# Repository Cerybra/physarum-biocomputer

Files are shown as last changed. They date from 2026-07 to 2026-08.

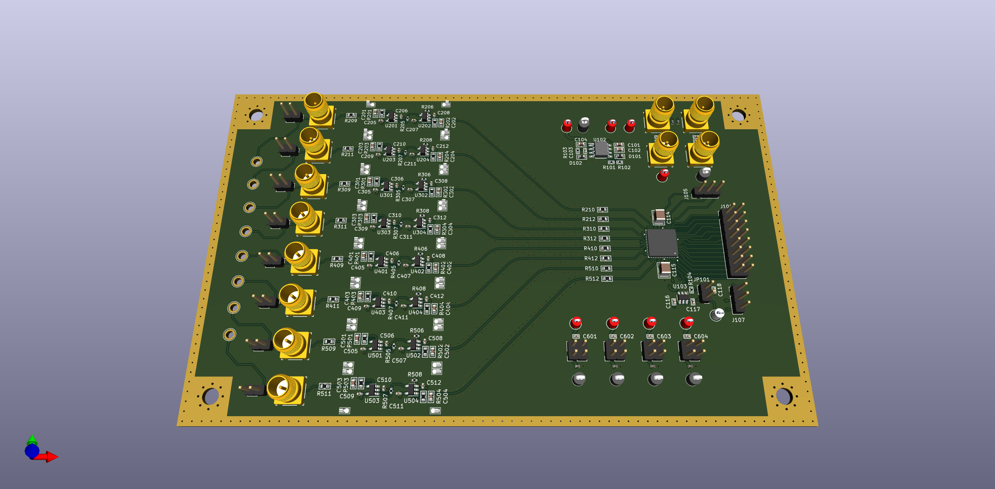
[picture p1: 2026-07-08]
modules/daq-eval-board/images/pcb/daq-eval-board-3d-[BARE].png

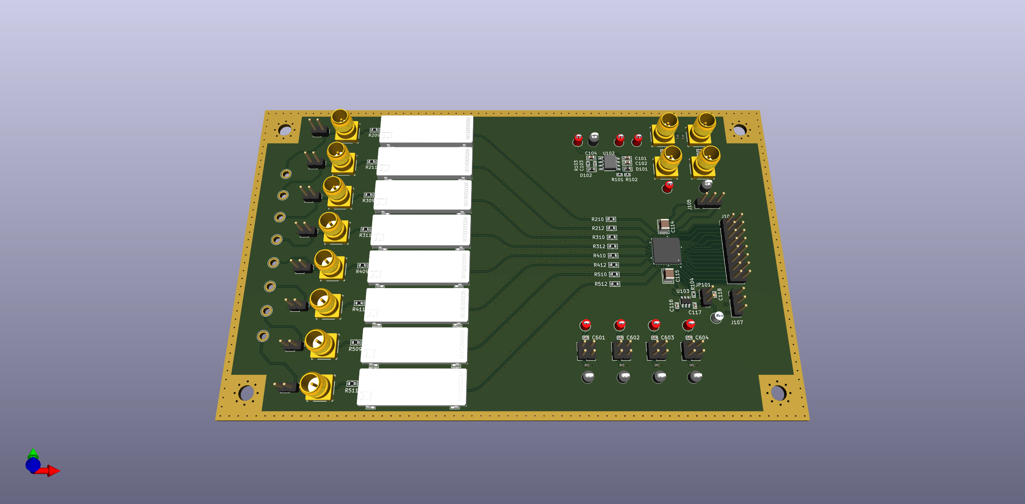
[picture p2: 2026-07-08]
modules/daq-eval-board/images/pcb/daq-eval-board-3d-[SHIELDED].png

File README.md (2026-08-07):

<div align="center">
	<h1>Physarum Biocomputer</h1>
</div>

<hr/>



<hr/>

## Project Structure

#### Descriptions

The project structure is organized as follows:

- 📂 `adaptors`: contains all of the hardware files for the various adaptors that are compatible with the biocomputer carrier board.

- 📂 `data`: contains all of the experimentally collected data.

- 📂 `devices`: contains all of the hardware files for both the open-air and enclosure-type devices.

- 📂 `modules`: contains all of the hardware files for each of the biocomputer modules.

- 📂 `software`: contains all of the software used in performing experiments.

- 📂 `simulations`: contains all of the code used in performing equivalent circuit simulations.

- 📂 `plots`: contains all of the code used in producing the main figures.

#### Structure
📂 `repository` 

- 📂 `data`
	- 📂 `device-pulse-recordings` 
	- 📂 `device-regression-recordings` 
	- 📂 `device-sweep-recordings` 
	- 📂 `eis-recordings`
	- 📂 `noise-recordings`
	- 📂 `reservoir-computing-recordings`
- 📂 `modules`
    - 📂 `biocomputer-eval-motherboard`
    - 📂 `dac-eval-module`
    - 📂 `daq-eval-board`
    - 📂 `dual-rail-power-eval-module`
    - 📂 `selector-eval-module`
- 📂 `adaptors`
    - 📂 `1x1-adaptor`
    - 📂 `4x1-adaptor`
	- 📂 `8x1-adaptor`
    - 📂 `card-half`
    - 📂 `card-full`
    - 📂 `configurable-adaptor`
    - 📂 `standard-adaptor`
- 📂 `software`
    - 📂 `examples`
- 📂 `devices`
    - 📂 `enclosures`
    - 📂 `pluggable`
- 📂 `simulations`
- 📂 `plots`

## Reproducibility

To reproduce all of the main figures, either clone the repository or download the `data` directory. Then, run each of the scripts within the `plots/main` directory.

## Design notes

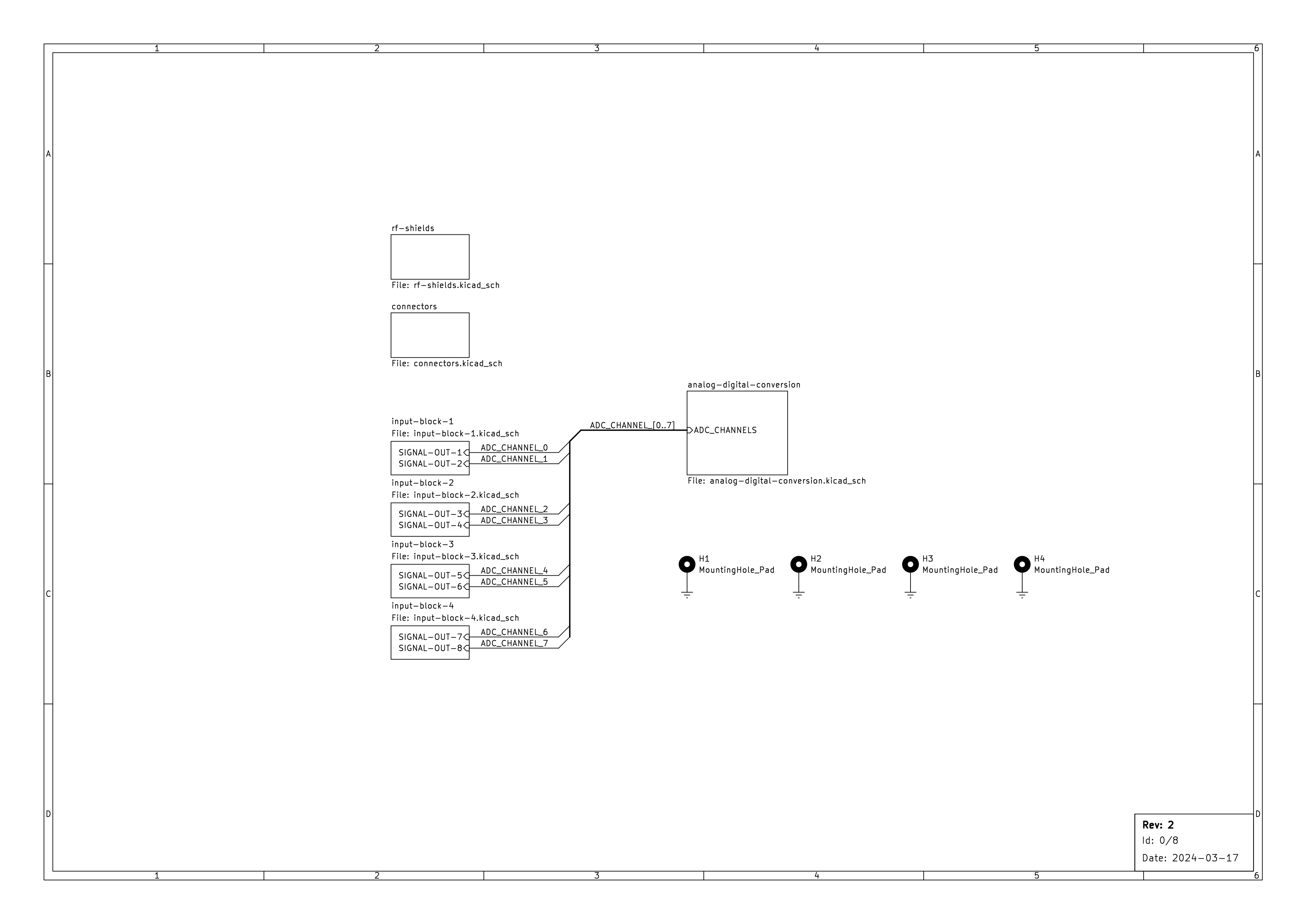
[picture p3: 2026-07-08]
modules/daq-eval-board/schematic/pages/[0]-root.png

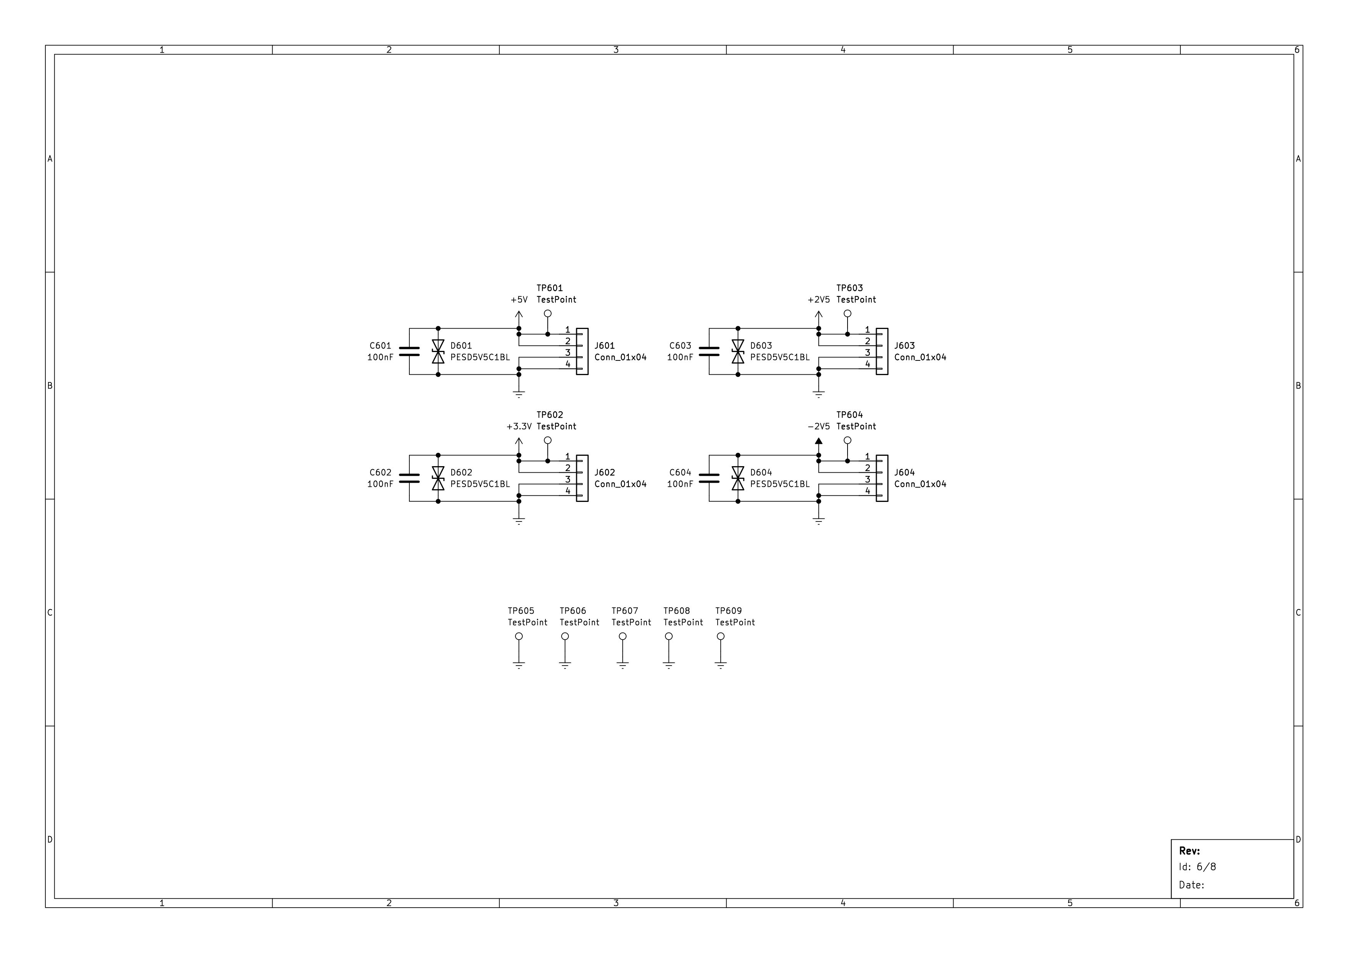
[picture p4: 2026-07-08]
modules/daq-eval-board/schematic/pages/[6]-connectors.png

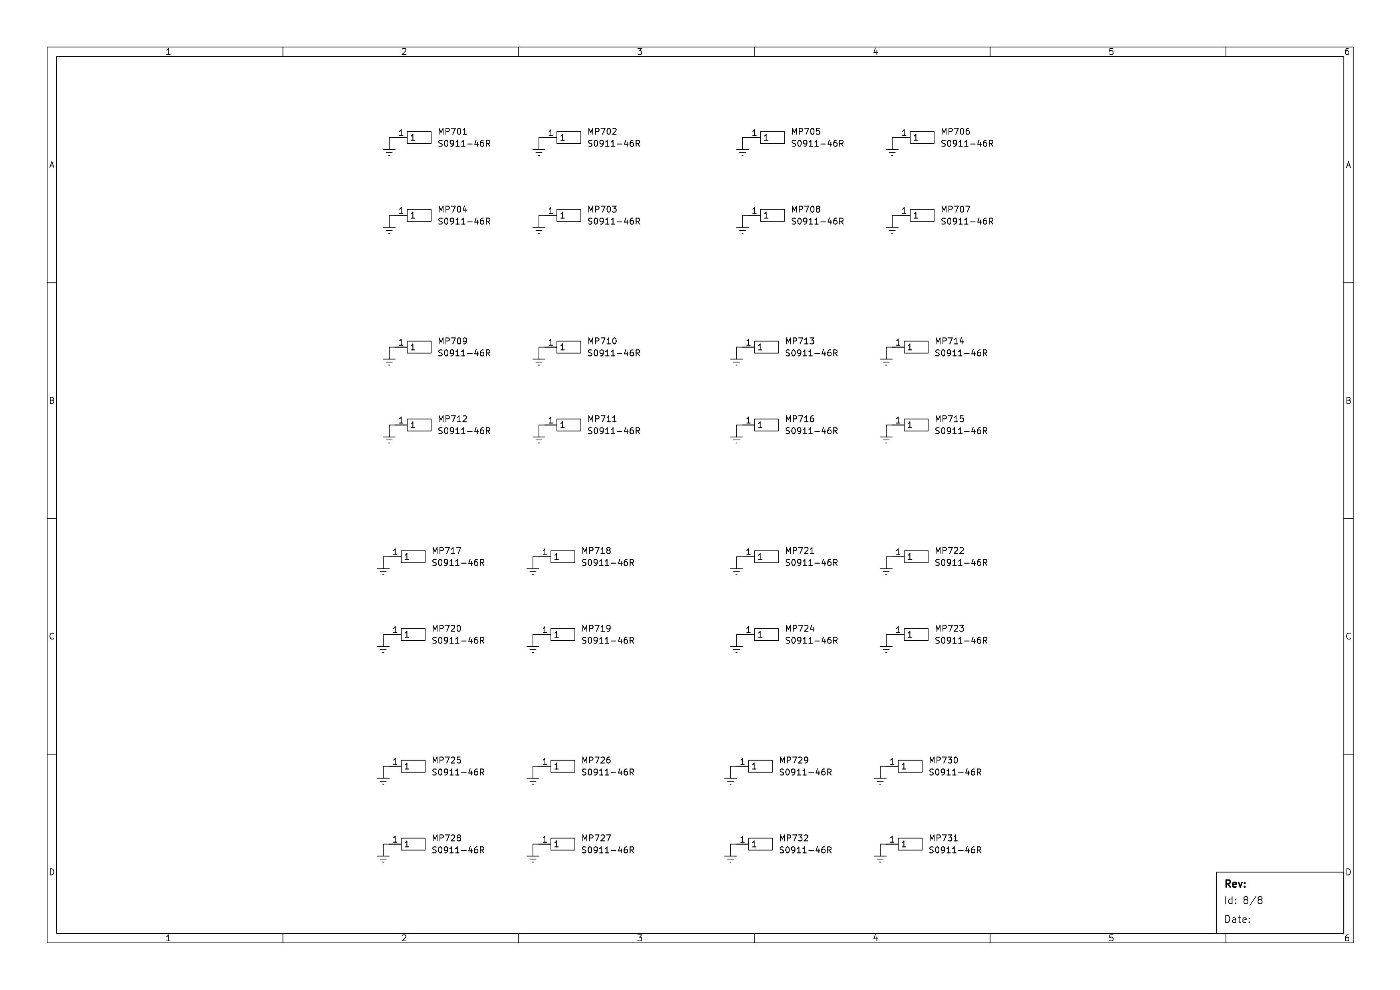
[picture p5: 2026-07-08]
modules/daq-eval-board/schematic/pages/[7]-rf-shields.png

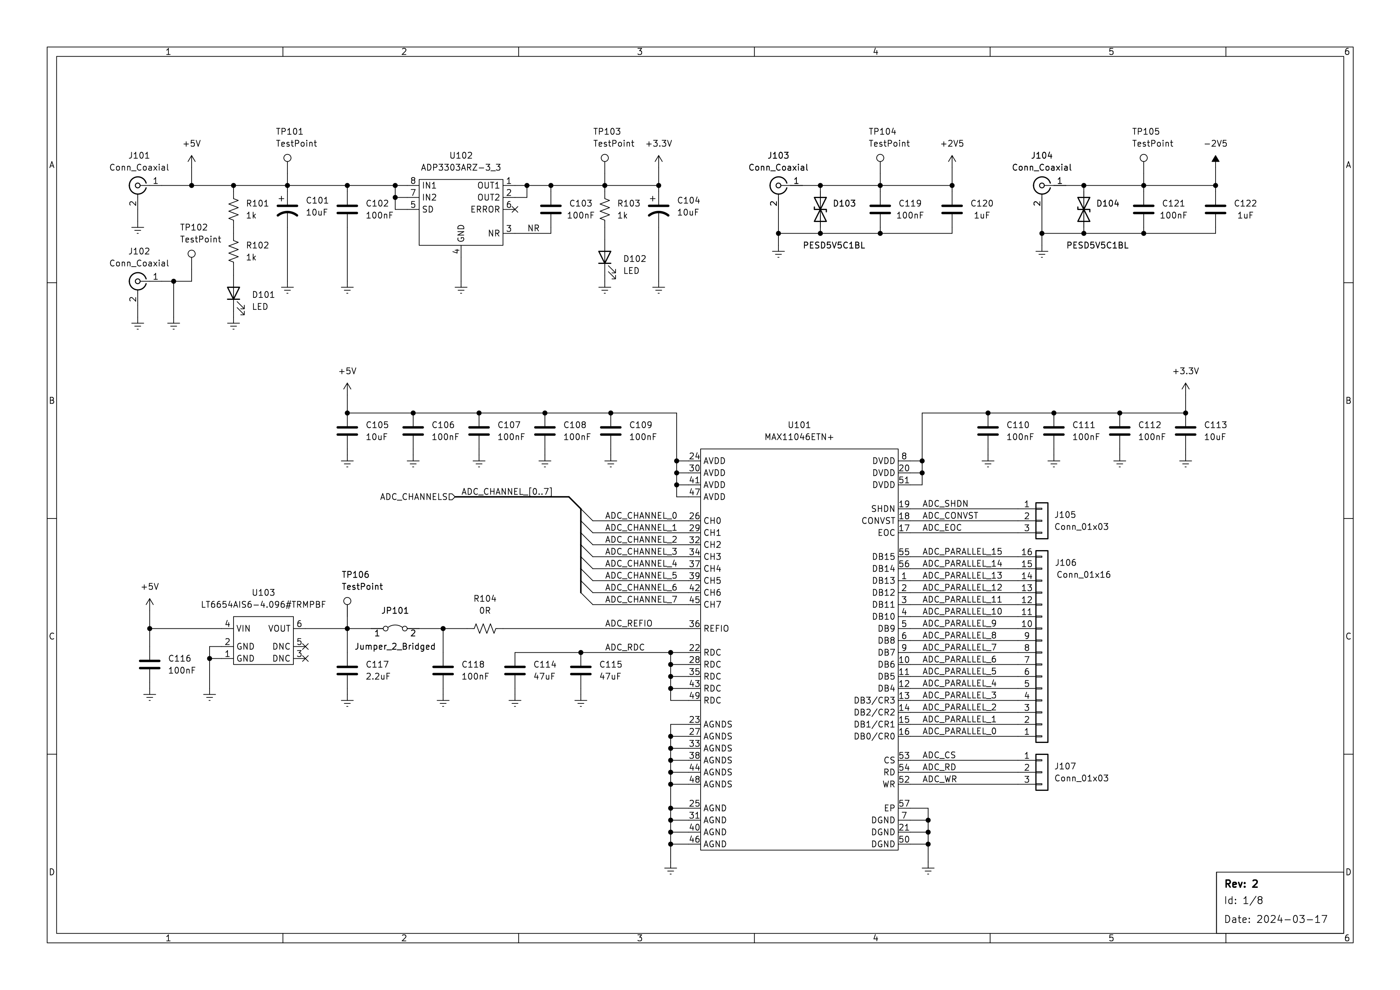
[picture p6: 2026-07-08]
modules/daq-eval-board/schematic/pages/[1]-analog-digital-conversion.png

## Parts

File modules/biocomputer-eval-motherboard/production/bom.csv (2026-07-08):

Comment | Designator | Footprint | LCSC Part #
100nF Unpolarized capacitor | C301,C302,C303,C304,C401,C501,C601,C602,C603,C604 | C_0603_1608Metric
Conn_Coaxial coaxial connector (BNC, SMA, SMB, SMC, Cinch/RCA, LEMO, ...) | J101,J102,J103,J104,J105,J106,J107,J108,J201,J202,J203,J204,J205,J206,J305,J306,J307,J308,J311,J312,J313,J314,J605,J606,J607,J608 | CONN_RF2-04A-T-00-50-G_ADM | C496549
10k Resistor, US symbol | R101,R102,R103,R104,R105,R106,R107,R108,R301,R302,R303,R304,R305,R306,R307,R308,R401,R402,R403,R404,R405,R406,R407,R408,R501,R502,R503,R504,R505,R506,R507,R508 | R_0603_1608Metric

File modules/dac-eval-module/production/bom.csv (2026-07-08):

Comment | Designator | Footprint | LCSC Part #
1uF Unpolarized capacitor | C101,C104,C106 | C_0402_1005Metric
100nF Unpolarized capacitor | C102,C103,C105,C107,C108,C109 | C_0402_1005Metric
LED Light emitting diode | D101 | LED_0603_1608Metric
Conn_Coaxial coaxial connector (BNC, SMA, SMB, SMC, Cinch/RCA, LEMO, ...) | J101,J102,J103,J104 | CONN_RF2-04A-T-00-50-G_ADM
1k Resistor, US symbol | R101 | R_0603_1608Metric
TestPoint test point | TP101,TP104,TP105 | KEYSTONE_5000
TestPoint test point | TP102 | KEYSTONE_5001
LTC2666IUH-16#PBF Octal 16-Bit/12-Bit ±10V VOUT SoftSpan DACs with 10ppm/°C Max Reference | U101 | QFN-32-1EP_5x5mm_P0.5mm_EP3.45x3.45mm

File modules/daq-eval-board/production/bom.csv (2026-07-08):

Comment | Designator | Footprint | LCSC Part #
10uF Unpolarized capacitor | C101,C104,C105,C113 | C_0603_1608Metric
100nF Unpolarized capacitor | C102 | C_0603_1608Metric
100nF Unpolarized capacitor | C103,C106,C107,C108,C109,C110,C111,C112,C116,C118,C119,C121,C205,C206,C207,C208,C209,C210,C211,C212,C305,C306,C307,C308,C309,C310,C311,C312,C405,C406,C407,C408,C409,C410,C411,C412,C505,C506,C507,C508,C509,C510,C511,C512,C601,C602,C603,C604 | C_0402_1005Metric
47uF Unpolarized capacitor | C114,C115 | C_1210_3225Metric
2.2uF Unpolarized capacitor | C117 | C_0402_1005Metric
1uF Unpolarized capacitor | C120,C122 | C_0402_1005Metric
10pF Unpolarized capacitor | C201,C202,C203,C204,C301,C302,C303,C304,C401,C402,C403,C404,C501,C502,C503,C504 | C_0603_1608Metric
LED Light emitting diode | D101,D102 | D_0603_1608Metric
PESD5V5C1BL Bidirectional transient-voltage-suppression diode | D103,D104,D601,D602,D603,D604 | SOD882D | C18212174
Conn_Coaxial coaxial connector (BNC, SMA, SMB, SMC, Cinch/RCA, LEMO, ...) | J101,J102,J103,J104,J201,J202,J301,J302,J401,J402,J501,J502 | CONN_RF2-04A-T-00-50-G_ADM
S0911-46R Shield Clip, SMT, Compact, Beryllium Copper, tin, Tape & Reeled | MP701,MP702,MP703,MP704,MP705,MP706,MP707,MP708,MP709,MP710,MP711,MP712,MP713,MP714,MP715,MP716,MP717,MP718,MP719,MP720,MP721,MP722,MP723,MP724,MP725,MP726,MP727,MP728,MP729,MP730,MP731,MP732 | S091146R | C3308714
1k Resistor, US symbol | R101,R102,R103 | R_0402_1005Metric
0R Resistor, US symbol | R104 | R_0402_1005Metric
10M Resistor, US symbol | R201,R203,R301,R303,R401,R403,R501,R503 | R_0603_1608Metric
1k Resistor, US symbol | R202,R204,R302,R304,R402,R404,R502,R504 | R_0603_1608Metric
100 Resistor, US symbol | R205,R206,R207,R208,R305,R306,R307,R308,R405,R406,R407,R408,R505,R506,R507,R508 | R_0402_1005Metric
0R Resistor, US symbol | R209,R210,R211,R212,R309,R310,R311,R312,R409,R410,R411,R412,R509,R510,R511,R512 | R_0603_1608Metric
TestPoint test point | TP101,TP103,TP104,TP105,TP601,TP602,TP603,TP604 | KEYSTONE_5000
TestPoint test point | TP102,TP605,TP606,TP607,TP608,TP609 | KEYSTONE_5001
TestPoint test point | TP106 | KEYSTONE_5002
MAX11046ETN+ 16 Bit, 8 Channel, Simultaneous-Sampling +/-5V ADC | U101 | TQFN-56-EP1_8.00x8.00mm_P0.5mm | C2673377
ADP3303ARZ-3_3 | U102 | SOIC127P600X175-8N | C730047
LT6654AIS6-4.096#TRMPBF 4.096V Precision Wide Supply High Output Drive Low Noise Reference | U103 | TSOT-23-6 | C673265
OPA392DBVT Precision, Low-Offset-Voltage, Low-Noise, Low-Input-Bias-Current, Rail-to-Rail I/O, e-trim™ Operational Amplifiers | U201,U203,U301,U303,U401,U403,U501,U503 | SOT-23-5
OPA387DBVR Ultra-High Precision, Zero-Drift, Low-Input-Bias-Current Op Amps | U202,U204,U302,U304,U402,U404,U502,U504 | SOT-23-5

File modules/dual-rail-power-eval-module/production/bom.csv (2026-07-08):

Comment | Designator | Footprint | LCSC Part #
10uF Unpolarized capacitor | C1,C2,C15,C16,C23,C24 | C_0805_2012Metric
1uF Unpolarized capacitor | C3 | C_0402_1005Metric
4.7uF Unpolarized capacitor | C4 | C_0402_1005Metric
22uF Unpolarized capacitor | C5,C6 | C_0805_2012Metric
100uF Unpolarized capacitor | C7,C8 | C_0805_2012Metric
10nF Unpolarized capacitor | C9,C10,C11,C12,C17,C18,C19,C20 | C_0402_1005Metric
100nF Unpolarized capacitor | C13,C14,C21,C22 | C_0402_1005Metric
Conn_Coaxial coaxial connector (BNC, SMA, SMB, SMC, Cinch/RCA, LEMO, ...) | J1,J2,J3,J4,J5,J6,J7,J8,J9,J10 | CONN_RF2-04A-T-00-50-G_ADM | C496549
100uH Inductor | L1,L2 | L_0805_2012Metric
221k Resistor | R1,R3 | R_0402_1005Metric
68k1 Resistor | R2 | R_0402_1005Metric
69k8 Resistor | R4 | R_0402_1005Metric
1.3 Resistor | R5,R6 | R_0805_2012Metric
47k Resistor | R7,R9 | R_0402_1005Metric
35k7 Resistor | R8,R10 | R_0402_1005Metric
97k6 Resistor | R11,R13 | R_0402_1005Metric
30k1 Resistor | R12,R14 | R_0402_1005Metric
TestPoint test point | TP1,TP2,TP3,TP4,TP5,TP6 | KEYSTONE_5000 | C5199900
TestPoint test point | TP7,TP8,TP9,TP10,TP11,TP12 | KEYSTONE_5006 | C2906764
LM27762 | U1 | DSS0012B
TPS7A4901DRBR 36-V, 150-mA, Ultralow-Noise, Positive Linear Regulator | U2,U4 | VSON-8
TPS7A3001DRBR –35-V, –200-mA, Ultralow-Noise, Negative Linear Regulator | U3,U5 | VSON-8

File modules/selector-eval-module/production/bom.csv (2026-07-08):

Comment | Designator | Footprint | LCSC Part #
100nF Unpolarized capacitor | C1,C2 | C_0402_1005Metric
TestPoint test point | TP1,TP2,TP3,TP4,TP5,TP6,TP7,TP8,TP9,TP10,TP11,TP12,TP13,TP14,TP15,TP16 | KEYSTONE_5002
TestPoint test point | TP18 | KEYSTONE_5000
TestPoint test point | TP19 | KEYSTONE_5006
MAX14662ETI+T 8xSPST Switch | U1 | TQFN-28-EP1_4.00x4.00mm_P5.0mm

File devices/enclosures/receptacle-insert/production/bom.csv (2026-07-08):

Comment | Designator | Quantity | Footprint | JLCPCB Part#
Conn_Coaxial | J1 | 1 | LINX_CONMCX001-SMD | C7542041

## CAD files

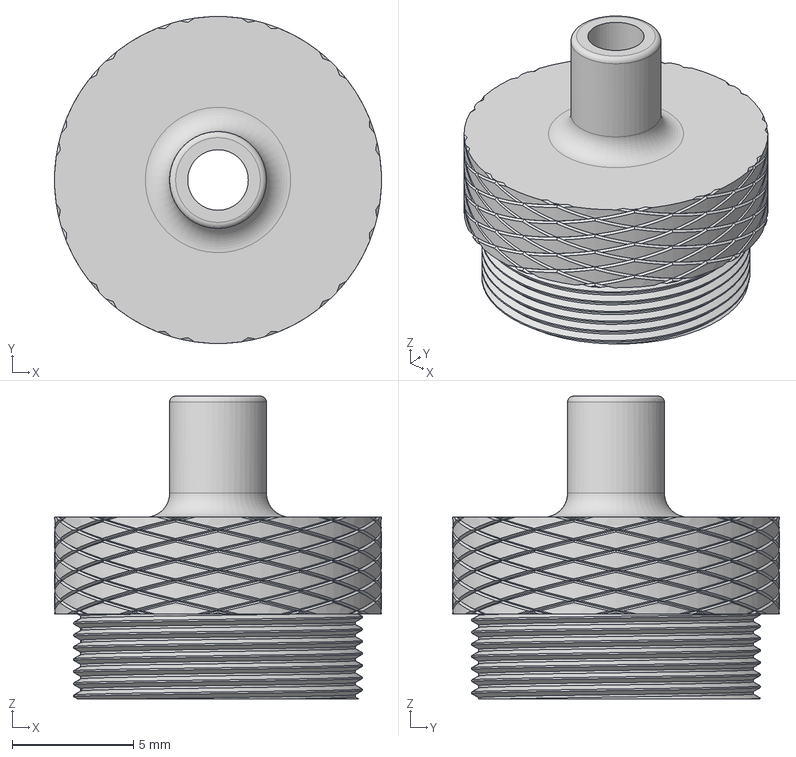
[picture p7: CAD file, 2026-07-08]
devices/enclosures/PHY10CMCX-CAP.step
13.5 x 13.5 x 12.5 mm

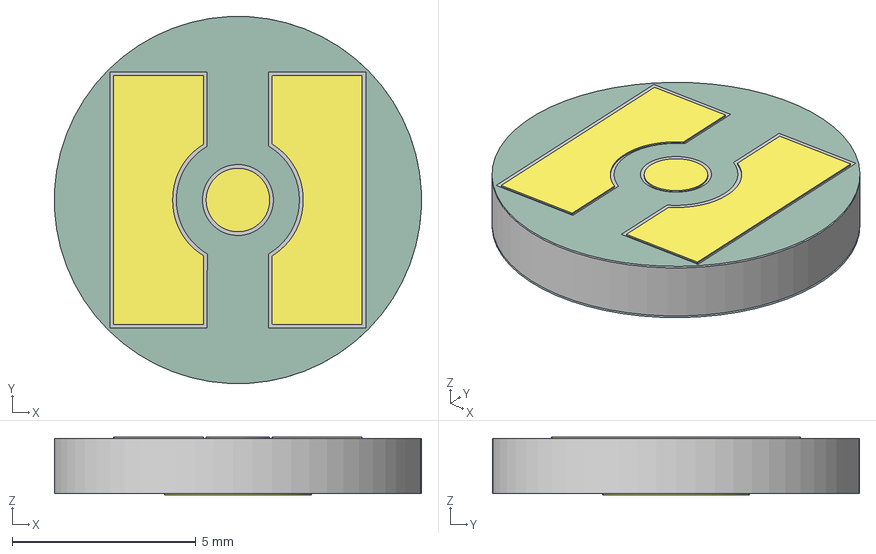
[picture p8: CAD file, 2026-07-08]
devices/enclosures/receptacle-insert/receptacle-insert.step
10.00 x 10.00 x 1.61 mm
neurophy-receptacle-insert_copper
neurophy-receptacle-insert_pad
neurophy-receptacle-insert_via
neurophy-receptacle-insert_soldermask
neurophy-receptacle-insert_PCB

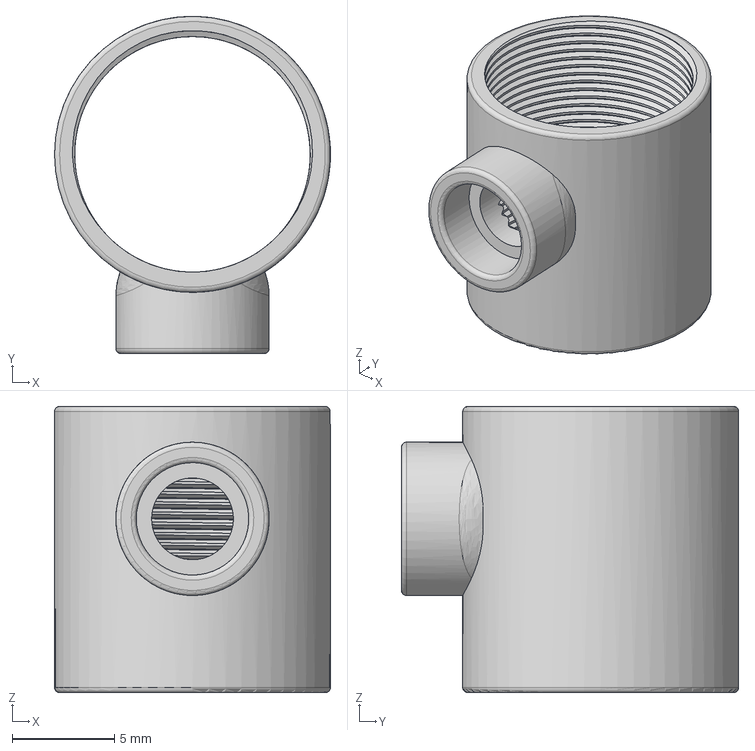
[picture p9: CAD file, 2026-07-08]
devices/enclosures/PHY10CMCX-BOD.step
13.5 x 16.5 x 14.0 mm

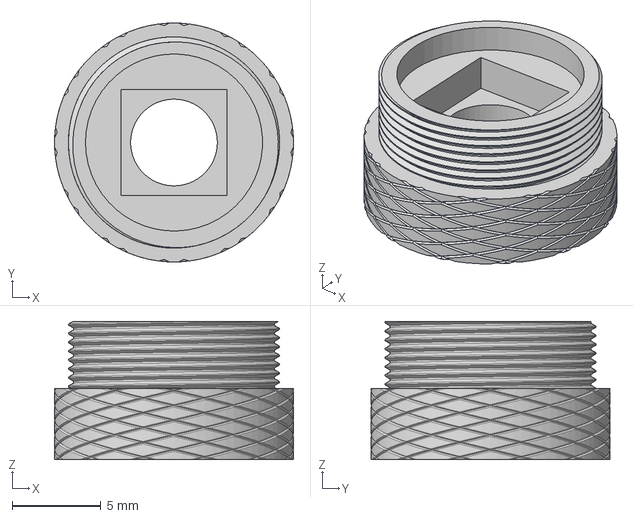
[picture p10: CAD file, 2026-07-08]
devices/enclosures/PHY10CMCX-BAS.step
13.5 x 13.5 x 7.80 mm

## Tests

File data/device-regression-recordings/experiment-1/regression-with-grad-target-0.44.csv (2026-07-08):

Prediction | Target | Weight | Update
0.029373646 | 0.06865412 | inf | -0.0
0.007858276 | 0.011972329 | 0.78582764 | -0.00012342156
0.010299683 | 0.101280734 | 0.51498413 | -0.005458863
0.018844604 | 0.03327339 | 0.6281535 | -0.0012985908
0.019913197 | 0.055114787 | 0.4978299 | -0.004224191
0.017623901 | 0.040227327 | 0.35247803 | -0.003390514
0.025864124 | 0.042314015 | 0.43106875 | -0.0029609802
0.032272816 | 0.09423871 | 0.46104023 | -0.0130128395
0.032120228 | 0.04725658 | 0.40150285 | -0.0036327248
0.036697865 | 0.10151105 | 0.40775403 | -0.01749956
0.050583363 | 0.09517956 | 0.5058336 | -0.0133788595
0.046768665 | 0.06288672 | 0.42516968 | -0.005318959
0.050583363 | 0.10452378 | 0.42152804 | -0.019418549
0.055466175 | 0.101967186 | 0.4266629 | -0.018135393
0.061112404 | 0.092291996 | 0.43651718 | -0.013095429
0.06507969 | 0.100026354 | 0.43386456 | -0.015726
0.0699625 | 0.15083435 | 0.43726563 | -0.038818486
0.07850742 | 0.15464982 | 0.46180835 | -0.038832624
0.08323765 | 0.11302735 | 0.46243137 | -0.016086439
0.07957554 | 0.15199044 | 0.41881862 | -0.041276496
0.09162998 | 0.107001275 | 0.4581499 | -0.009222776
0.08583164 | 0.14275342 | 0.40872213 | -0.03586072
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

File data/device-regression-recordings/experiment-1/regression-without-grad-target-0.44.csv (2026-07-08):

Prediction | Target | Weight | Update
0.0090789795 | 0.08966889 | inf | -0.0
0.0061798096 | 0.057032533 | 0.61798096 | -0.0015255817
0.007858276 | 0.047141775 | 0.39291382 | -0.0023570098
0.011062622 | 0.021911627 | 0.3687541 | -0.00097641035
0.0064849854 | 0.020091936 | 0.16212463 | -0.0016328341
0.009841919 | 0.09460816 | 0.19683838 | -0.012714936
0.009994507 | 0.06902269 | 0.16657512 | -0.010625073
0.002822876 | 0.08094457 | 0.0403268 | -0.016405556
0.008773804 | 0.08809852 | 0.10967255 | -0.01903793
0.012283325 | 0.08575383 | 0.13648139 | -0.019837037
0.008773804 | 0.05751185 | 0.08773804 | -0.014621415
0.013809204 | 0.098152764 | 0.12553822 | -0.027833374
0.0077056885 | 0.068675324 | 0.06421407 | -0.021949068
0.008773804 | 0.14238703 | 0.0674908 | -0.052109156
0.0064849854 | 0.13073173 | 0.046321325 | -0.052183636
0.0090789795 | 0.08253277 | 0.060526527 | -0.033054207
0.011062622 | 0.0738371 | 0.06914139 | -0.03013175
0.007858276 | 0.11394061 | 0.046225153 | -0.05410199
0.0077056885 | 0.12937362 | 0.04280938 | -0.06570069
0.005264282 | 0.14657618 | 0.02770675 | -0.08054778
0.013809204 | 0.13623911 | 0.06904602 | -0.07345795
0.008621216 | 0.10878961 | 0.04105341 | -0.06310609
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

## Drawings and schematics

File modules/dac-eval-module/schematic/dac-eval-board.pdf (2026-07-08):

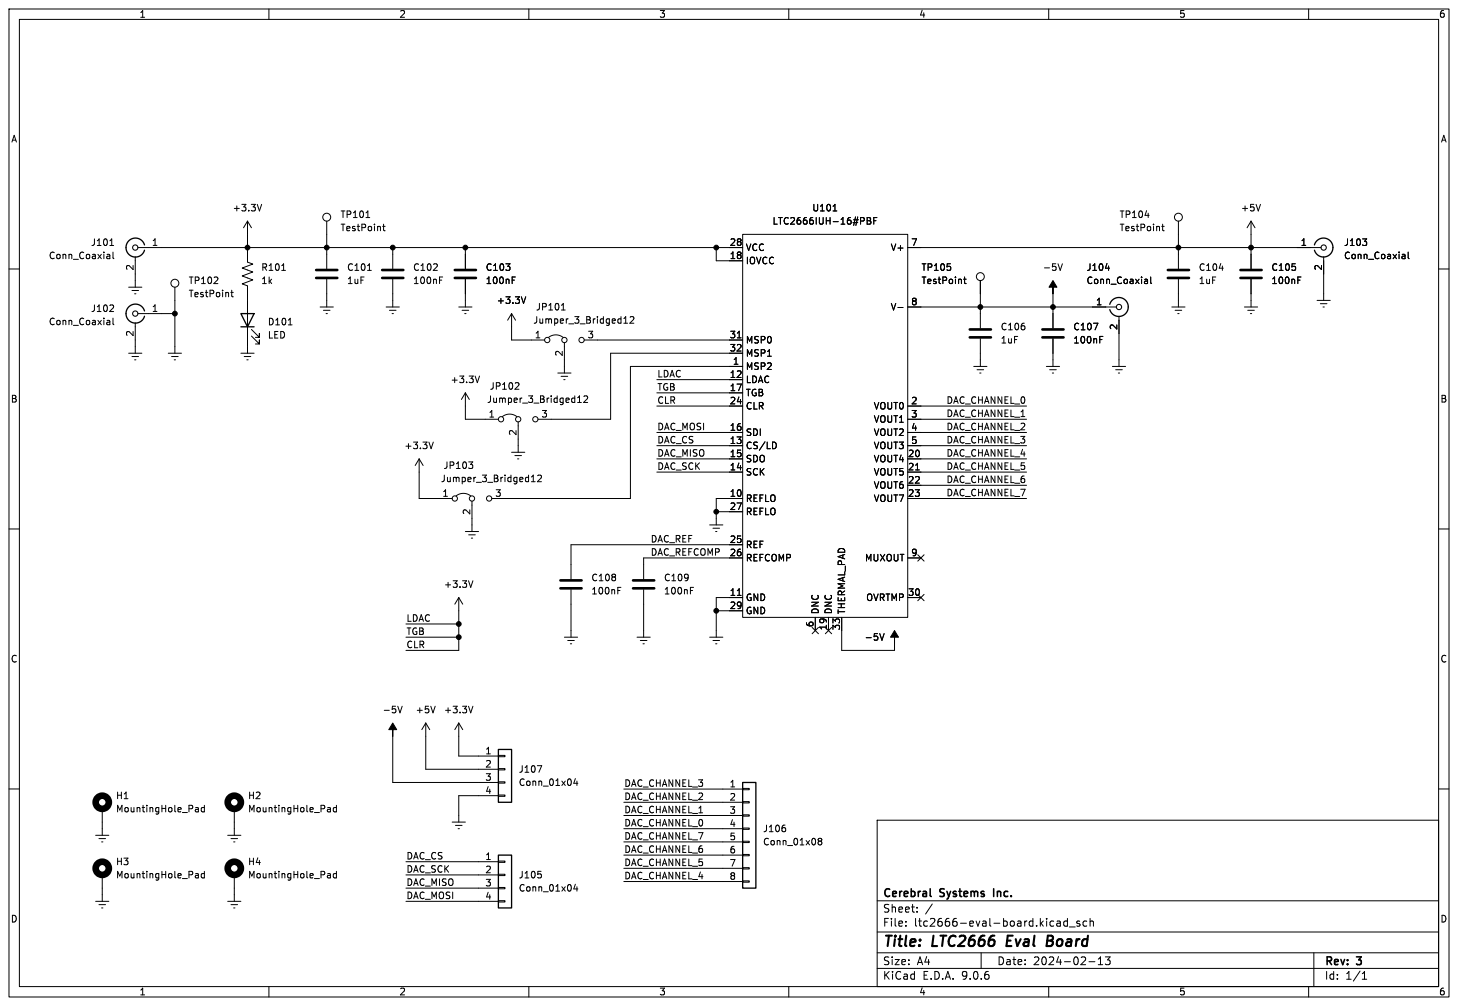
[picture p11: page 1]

Id: 1/1 Title: LTC2666 Eval Board

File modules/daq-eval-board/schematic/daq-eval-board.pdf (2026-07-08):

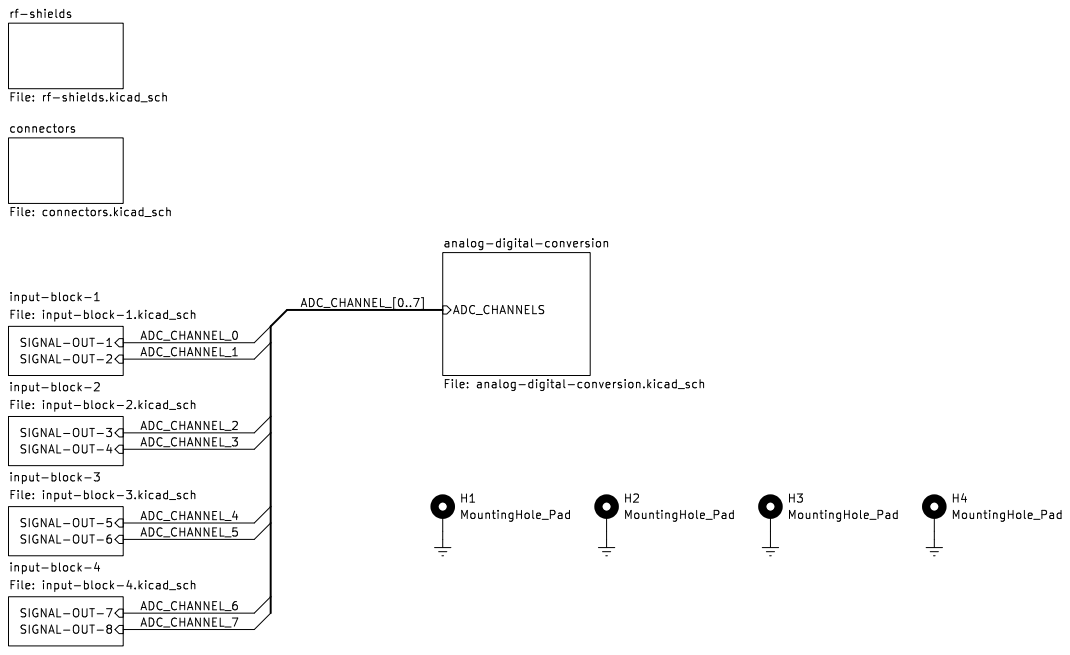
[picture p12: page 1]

connectors File: connectors.kicad_sch SIGNAL-OUT-8 SIGNAL-OUT-7

analog-digital-conversion File: analog-digital-conversion.kicad_sch

input-block-1 File: input-block-1.kicad_sch

SIGNAL-OUT-2 SIGNAL-OUT-1

input-block-3 File: input-block-3.kicad_sch SIGNAL-OUT-4 SIGNAL-OUT-3

input-block-4 File: input-block-4.kicad_sch SIGNAL-OUT-6 SIGNAL-OUT-5

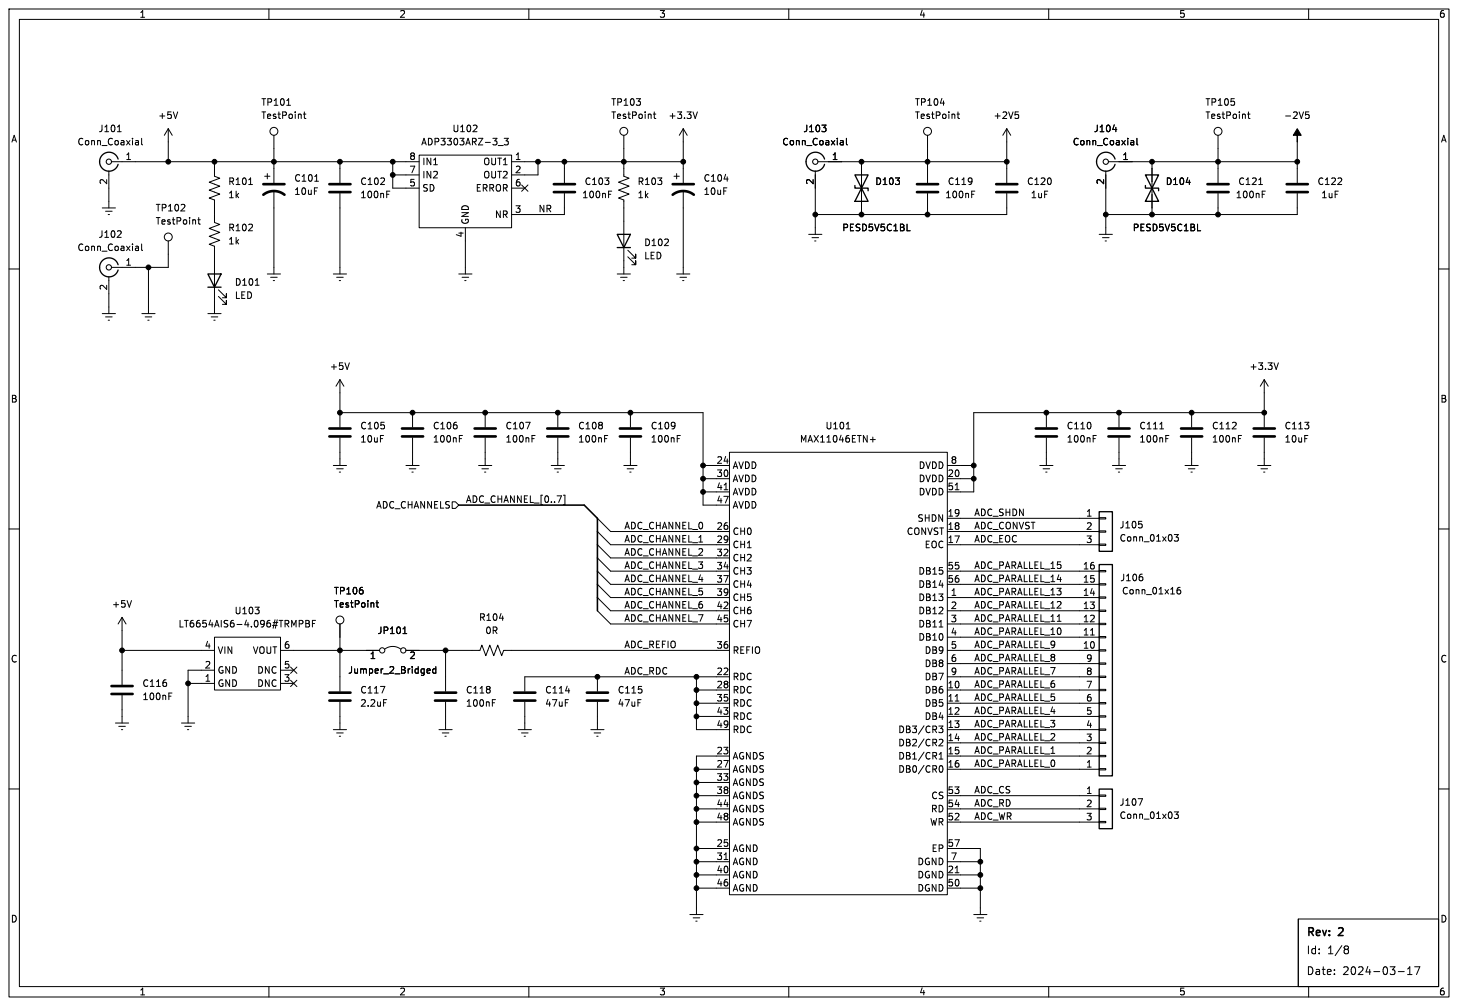
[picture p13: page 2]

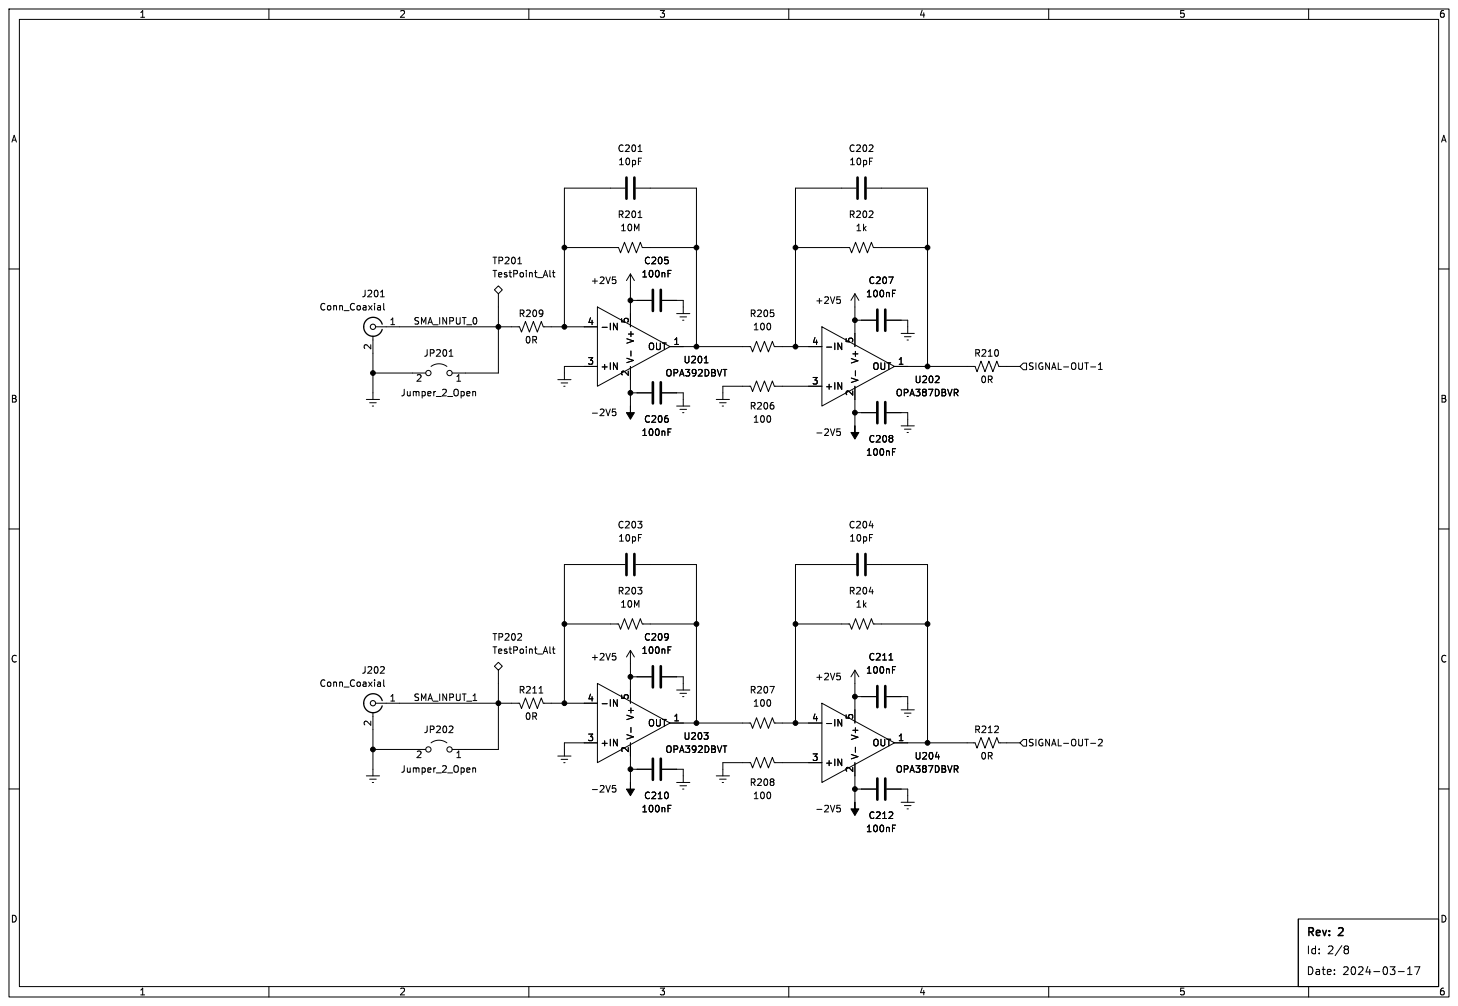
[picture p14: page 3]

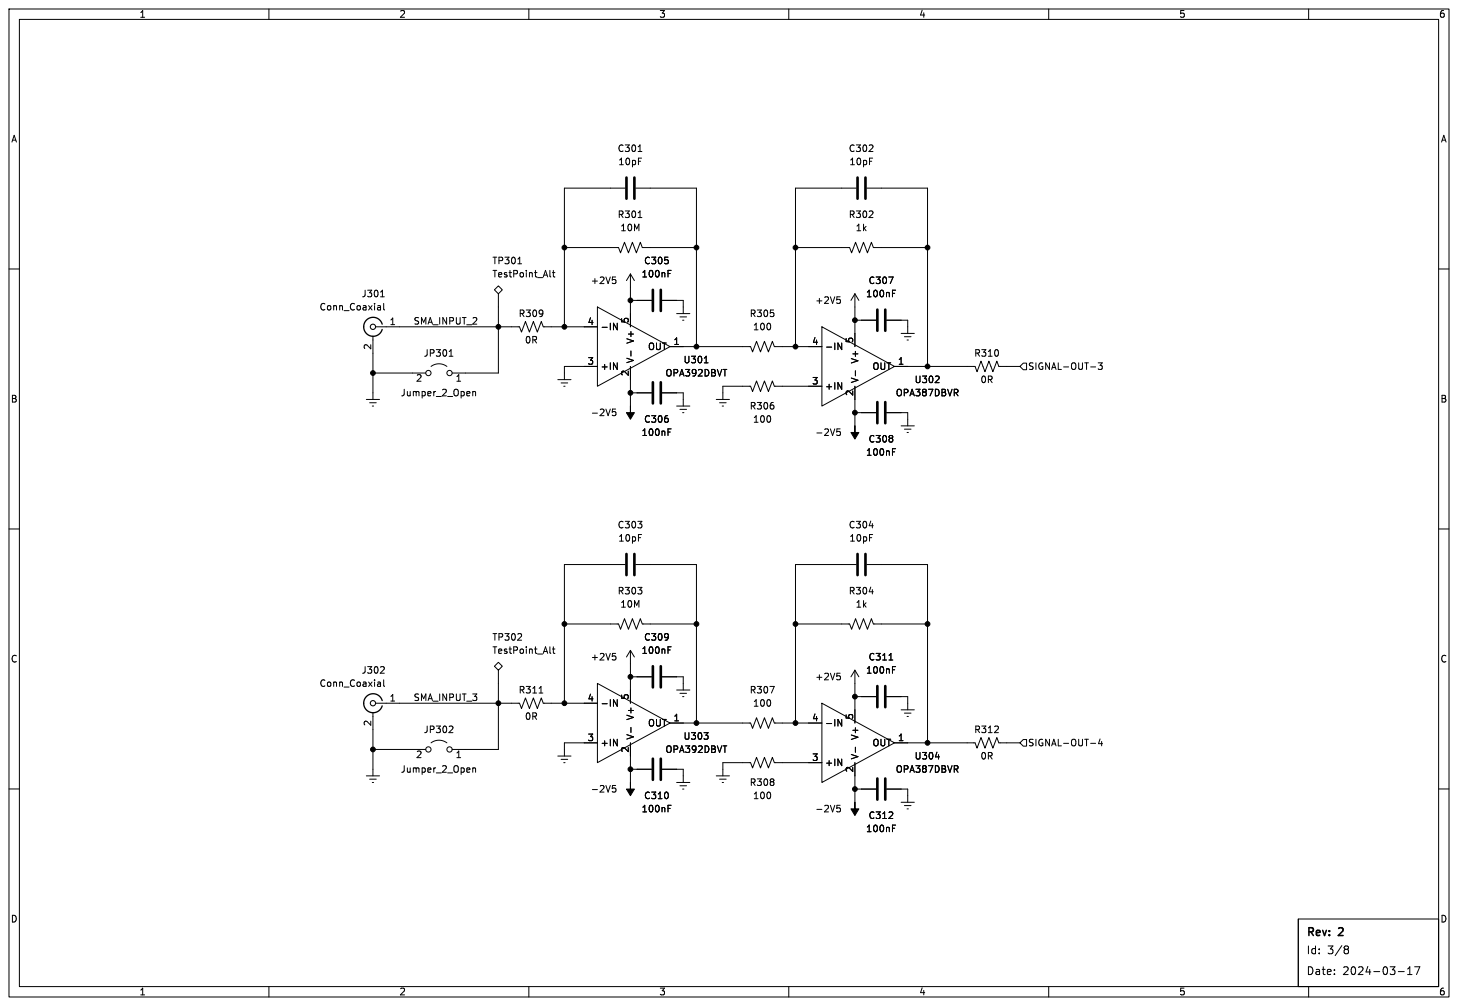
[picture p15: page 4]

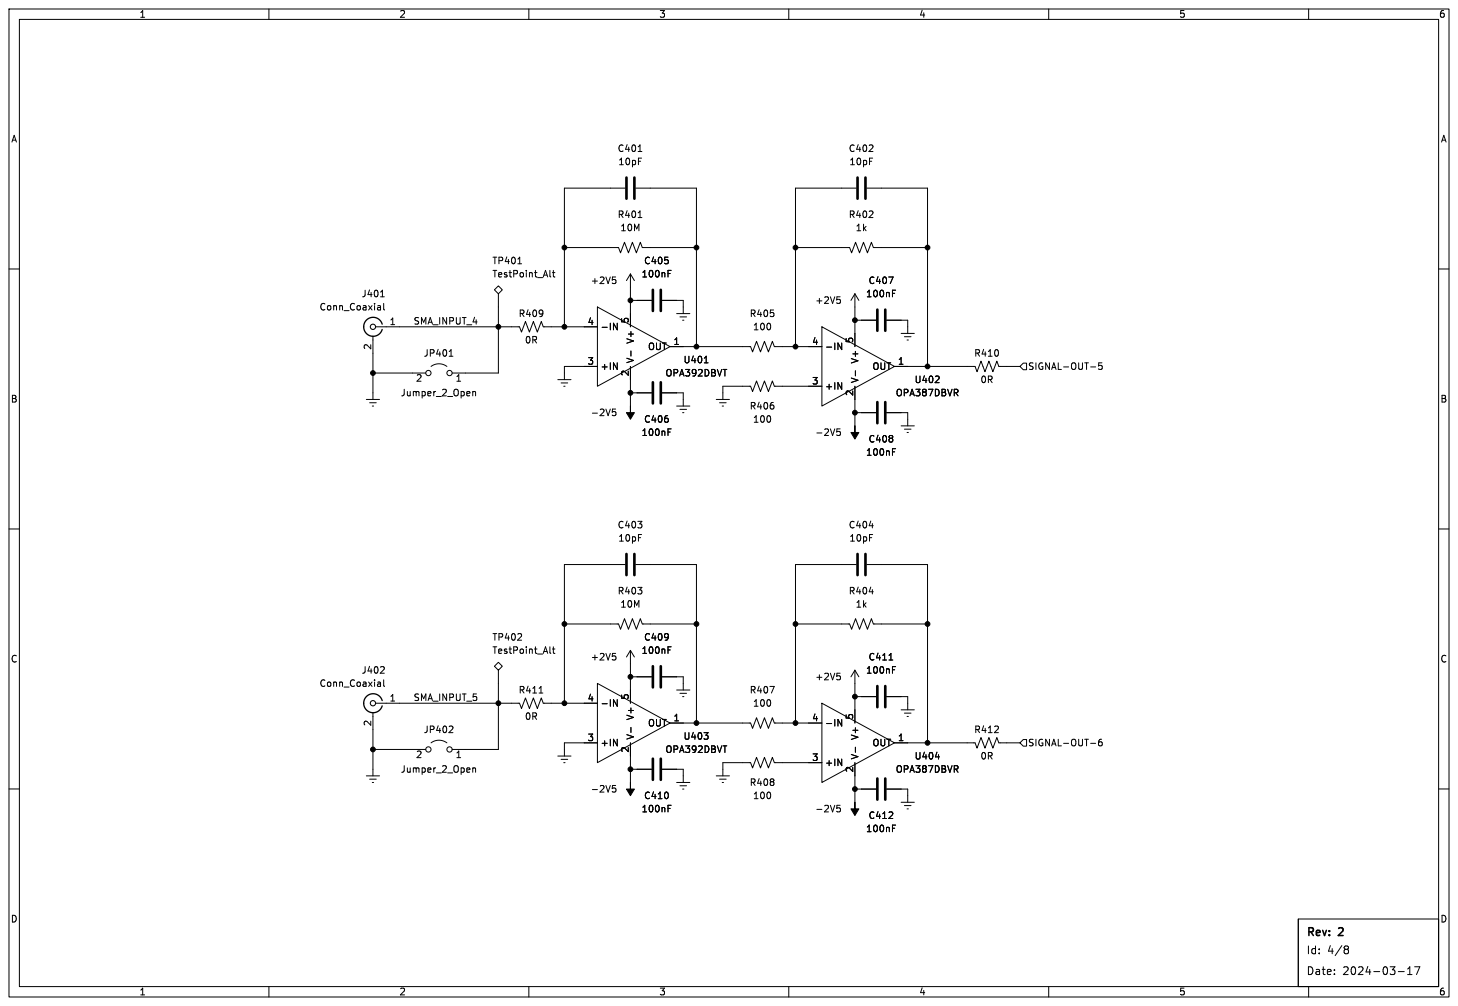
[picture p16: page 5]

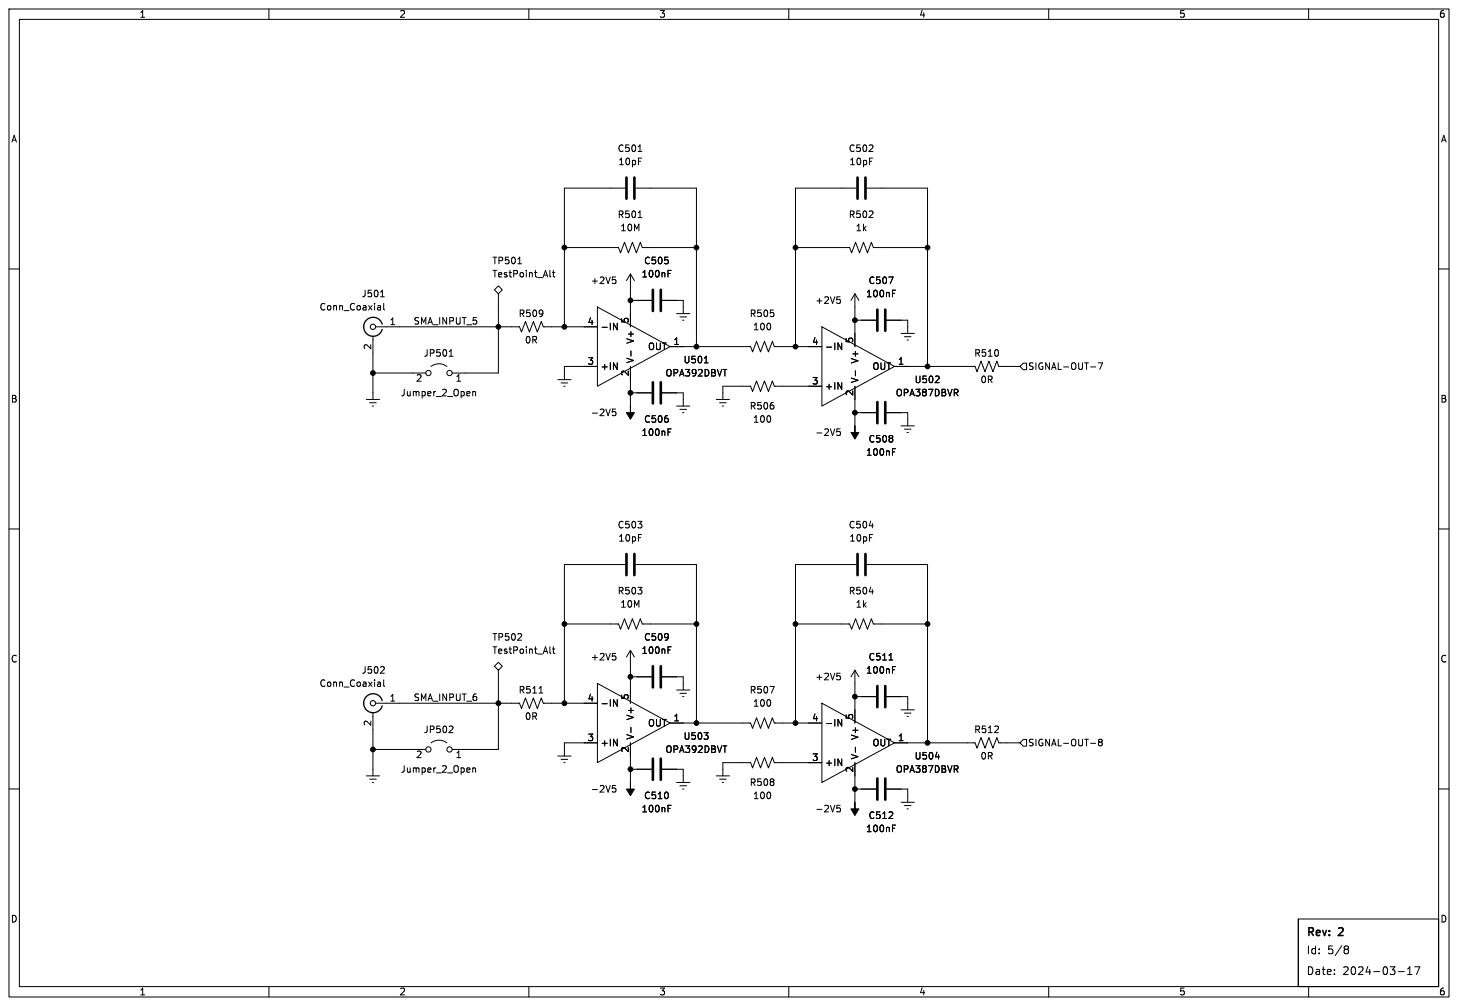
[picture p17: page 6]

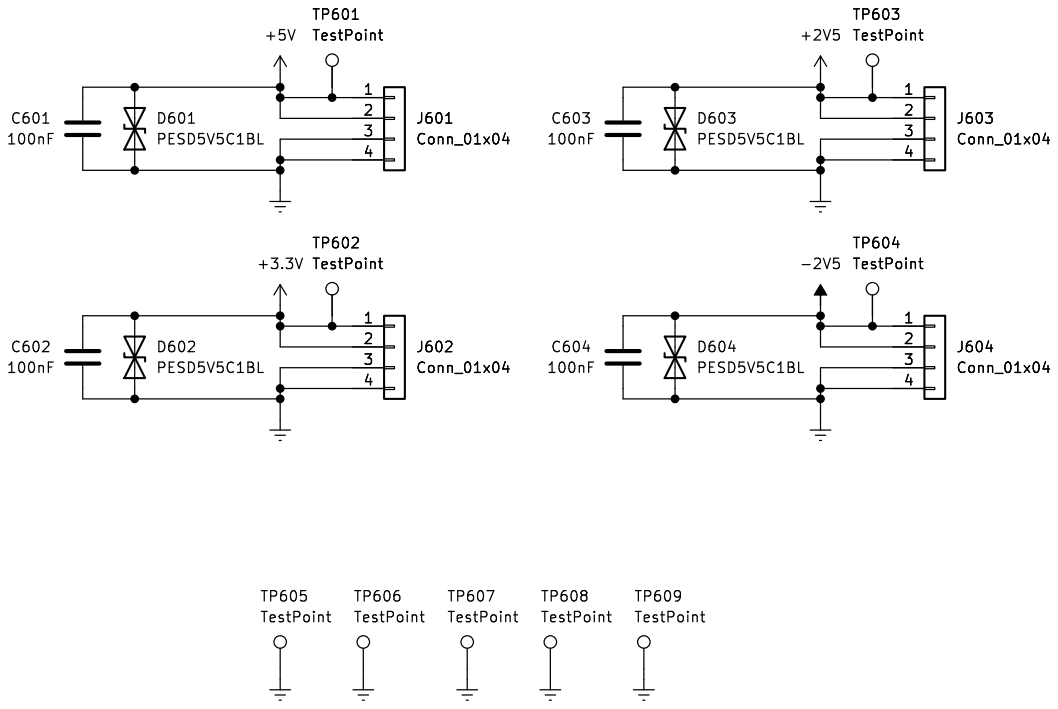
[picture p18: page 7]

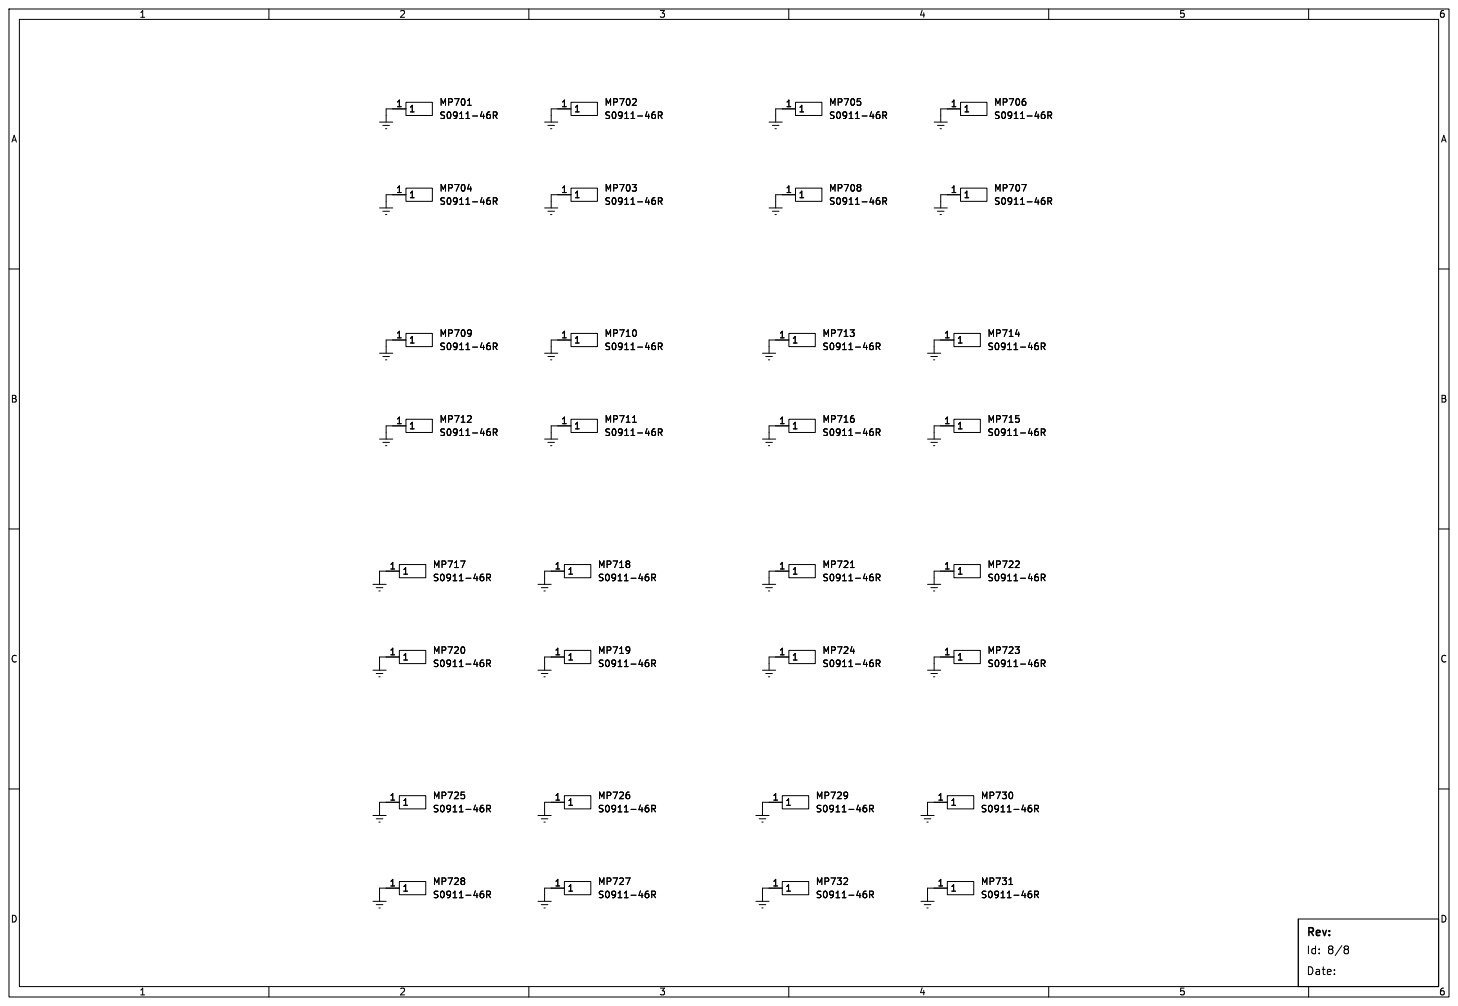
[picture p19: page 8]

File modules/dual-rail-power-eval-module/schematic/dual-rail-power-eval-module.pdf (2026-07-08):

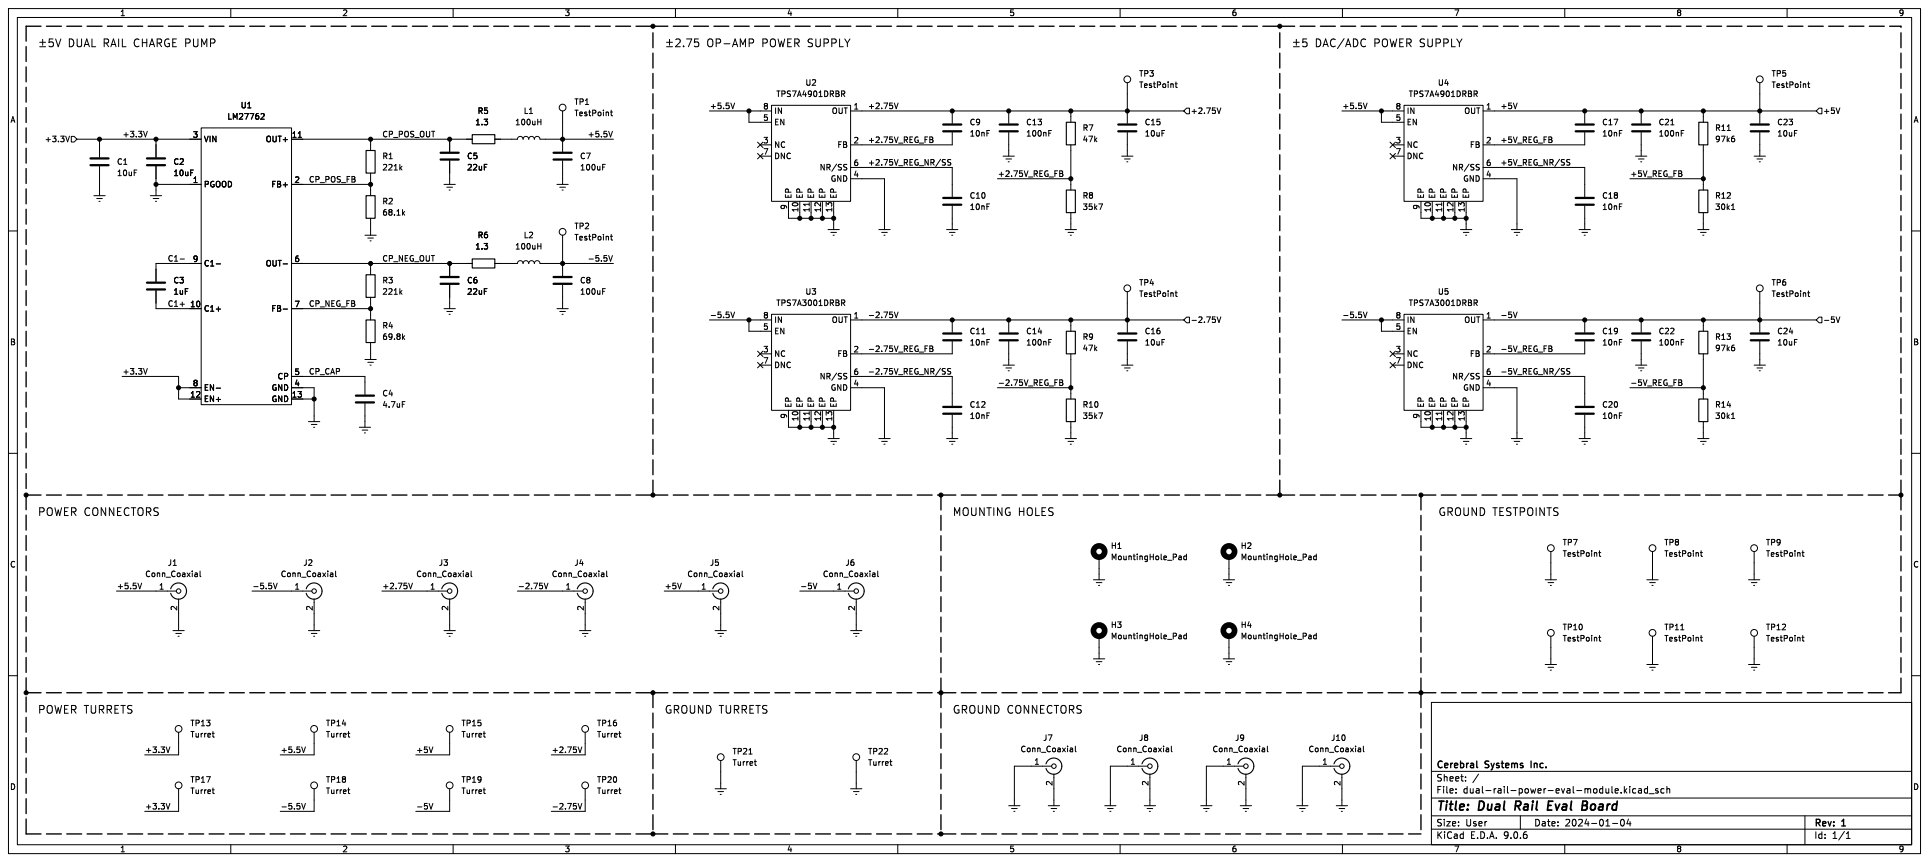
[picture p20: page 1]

þÿ±5VDUAL RAIL CHARGE PUMP

þÿ±2.75OP-AMP POWER SUPPLY

þÿ±5DAC/ADC POWER SUPPLY

9 EP 10 EP 11 EP 12 EP 13 OUT 1 FB 2 NR/SS 6 GND 4 U2 TPS7A4901DRBR

9 EP 10 EP 11 EP 12 EP 13 OUT 1 FB 2 NR/SS 6 GND 4 U4 TPS7A4901DRBR

9 EP 10 EP 11 EP 12 EP 13 OUT 1 FB 2 NR/SS 6 GND 4 U3 TPS7A3001DRBR

9 EP 10 EP 11 EP 12 EP 13 OUT 1 FB 2 NR/SS 6 GND 4 U5 TPS7A3001DRBR

Id: 1/1 Title: Dual Rail Eval Board

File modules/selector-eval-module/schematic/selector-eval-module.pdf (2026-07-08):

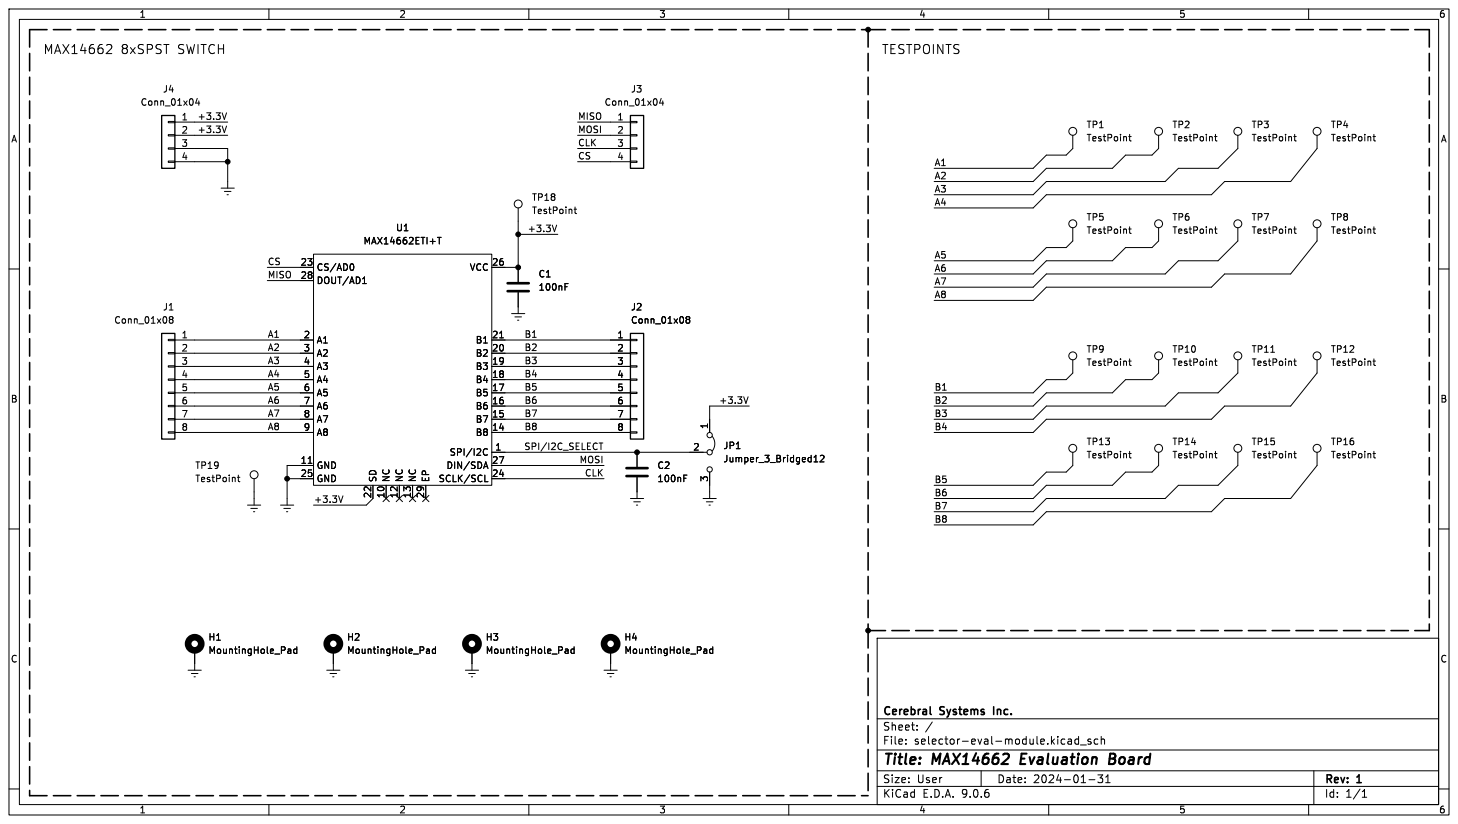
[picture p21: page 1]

Id: 1/1 Title: MAX14662 Evaluation Board

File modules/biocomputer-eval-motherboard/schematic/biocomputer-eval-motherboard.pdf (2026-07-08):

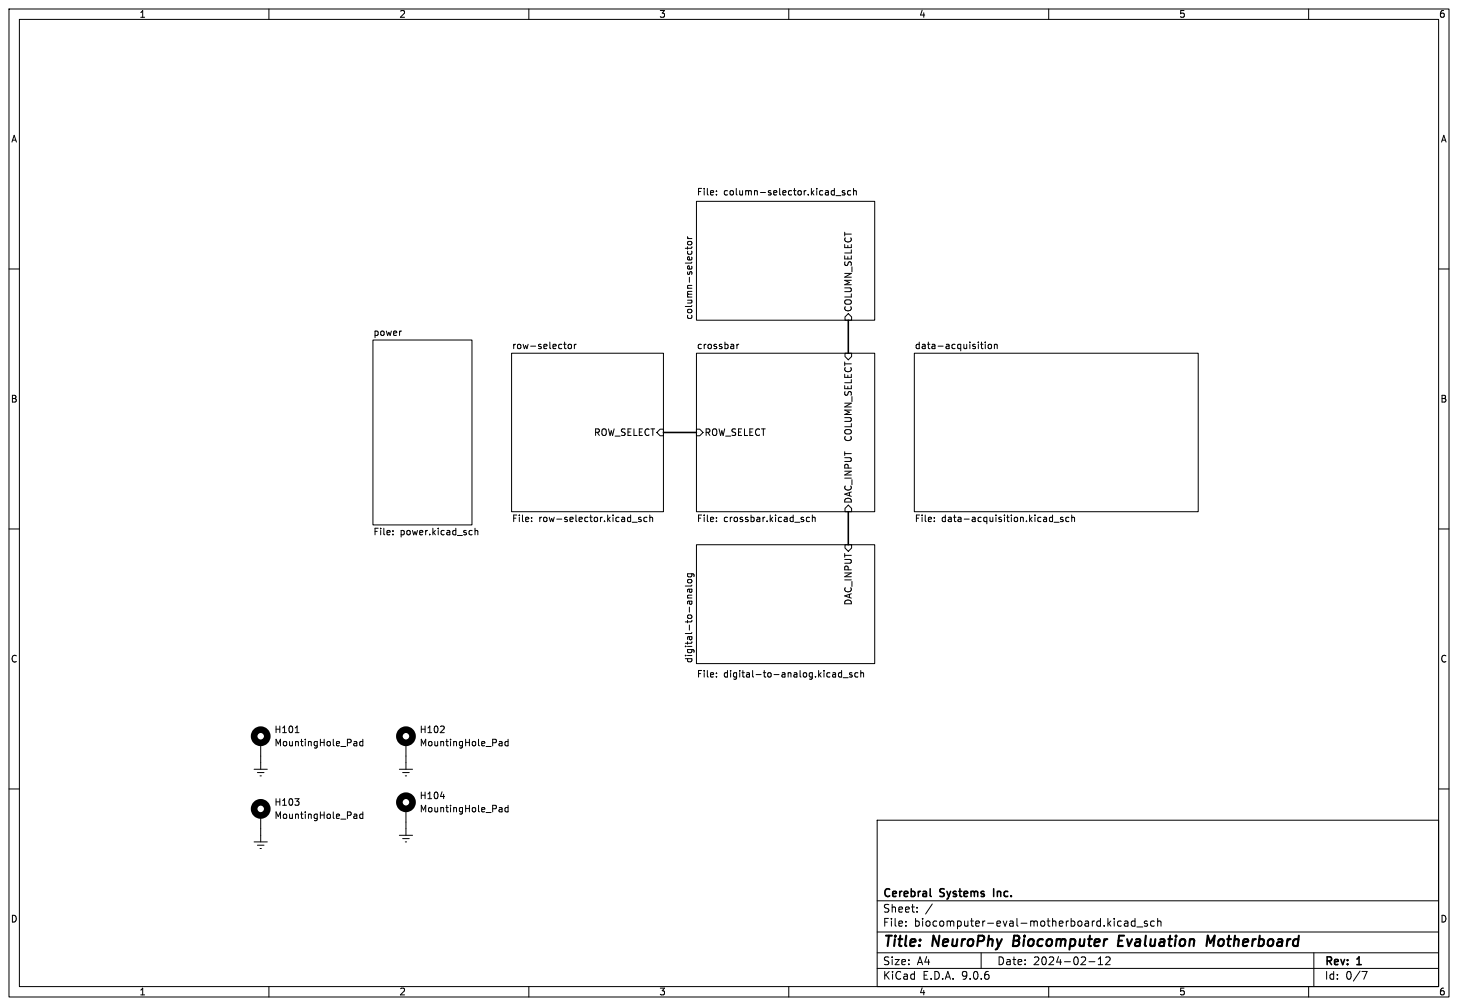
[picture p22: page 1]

Id: 0/7 Title: NeuroPhy Biocomputer Evaluation Motherboard


Id: 1/7 Title: NeuroPhy Evaluation Motherboard


Id: 2/7 Title: NeuroPhy Evaluation Motherboard


Id: 3/7 Title: NeuroPhy Evaluation Motherboard


Id: 4/7 Title: NeuroPhy Evaluation Motherboard


Id: 5/7 Title: NeuroPhy Evaluation Motherboard


Id: 6/7 Title: NeuroPhy Evaluation Motherboard

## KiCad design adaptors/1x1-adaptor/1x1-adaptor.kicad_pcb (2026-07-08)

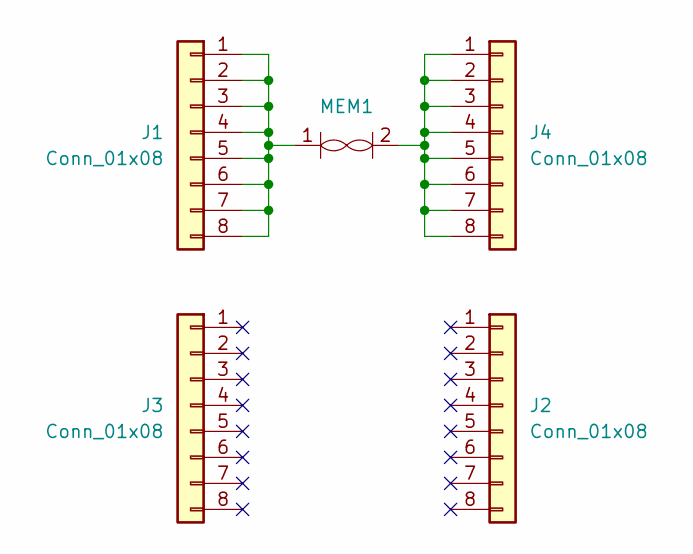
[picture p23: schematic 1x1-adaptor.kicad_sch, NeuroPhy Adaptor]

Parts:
J1, J2, J3, J4: Conn_01x08; PinHeader_1x08_P2.54mm_Vertical
MEM1: NeuroPhy_Memristor_5x5mm

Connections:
unnamed: J1.1, J1.2, J1.3, J1.4, J1.5, J1.6, J1.7, J1.8, MEM1.1
unnamed: J4.1, J4.2, J4.3, J4.4, J4.5, J4.6, J4.7, J4.8, MEM1.2

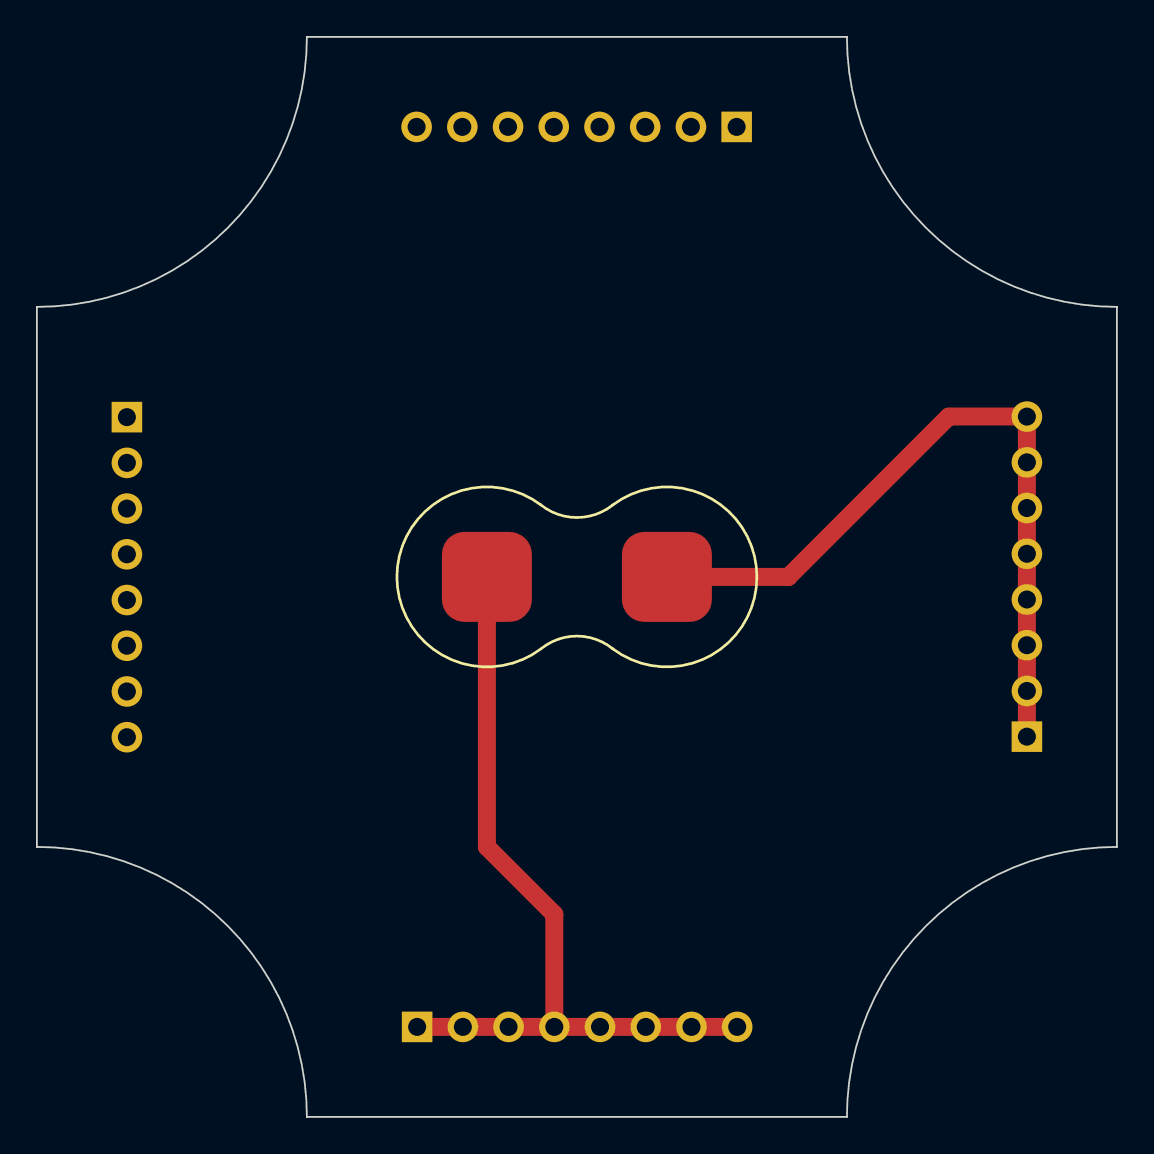
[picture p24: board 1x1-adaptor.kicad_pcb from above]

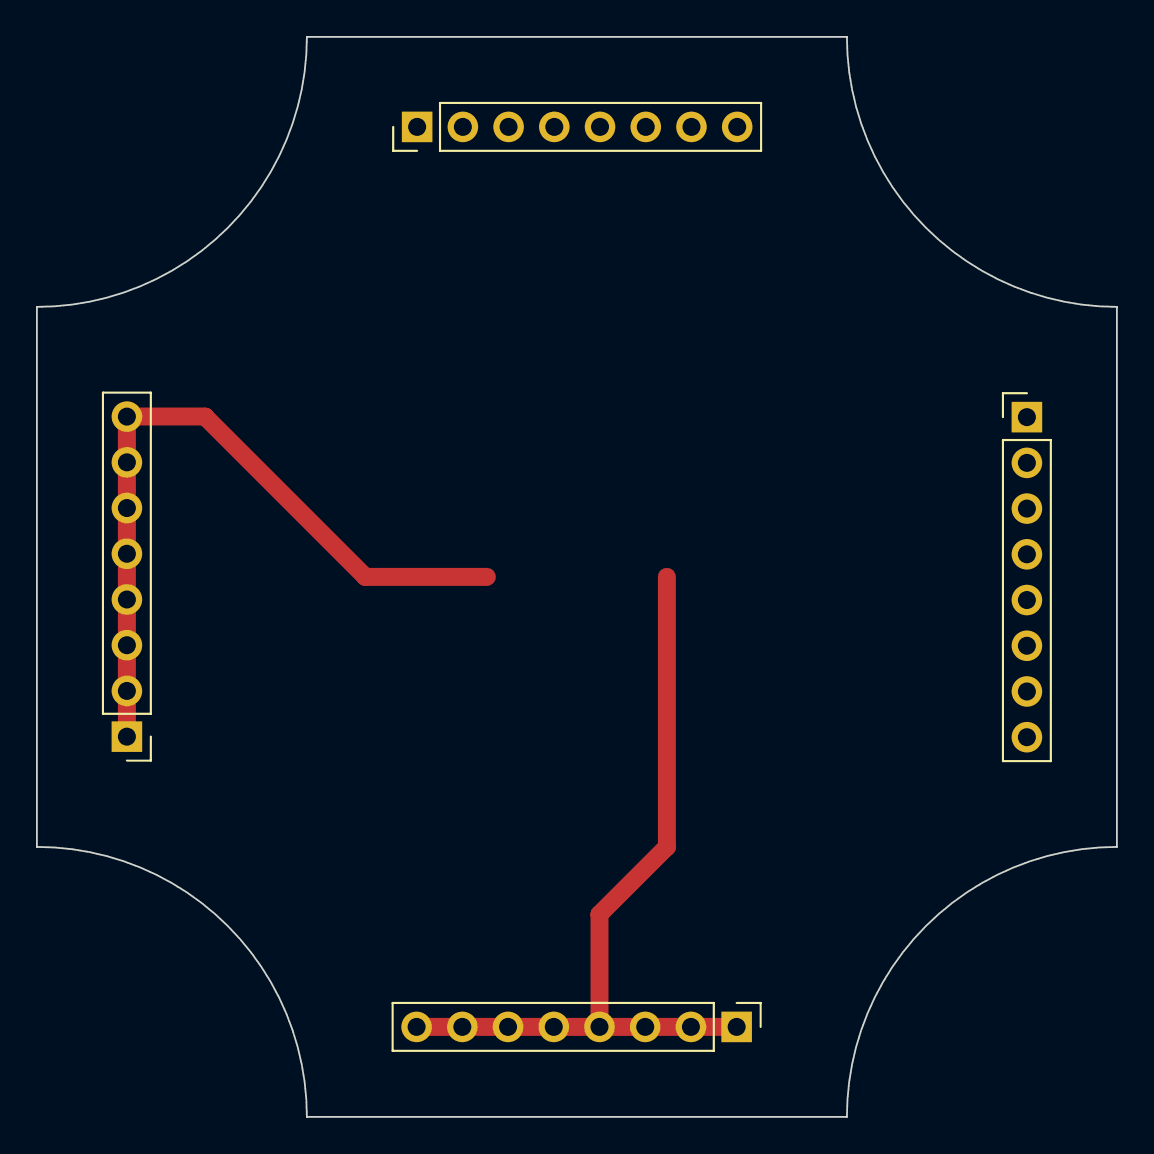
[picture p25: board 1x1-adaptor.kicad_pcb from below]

Board: 2 copper layers, 60.0 x 60.0 mm, 5 parts (4 on the bottom side), 2 nets.

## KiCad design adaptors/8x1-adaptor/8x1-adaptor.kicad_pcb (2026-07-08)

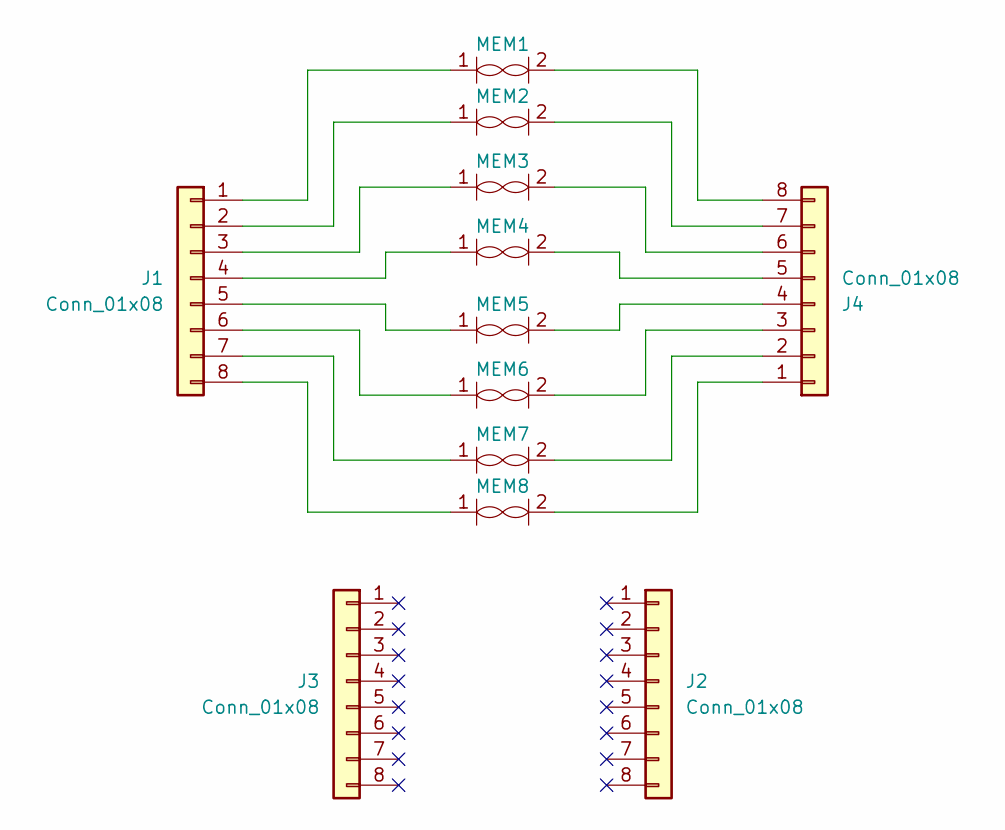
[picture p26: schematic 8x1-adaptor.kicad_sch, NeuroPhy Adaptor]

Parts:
J1, J2, J3, J4: Conn_01x08; PinHeader_1x08_P2.54mm_Vertical
MEM1, MEM2, MEM3, MEM4, MEM5, MEM6, MEM7, MEM8: NeuroPhy_Memristor_5x5mm

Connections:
unnamed: J1.1, MEM1.1
unnamed: J1.2, MEM2.1
unnamed: J1.3, MEM3.1
unnamed: J1.4, MEM4.1
unnamed: J1.5, MEM5.1
unnamed: J1.6, MEM6.1
unnamed: J1.7, MEM7.1
unnamed: J1.8, MEM8.1
unnamed: J4.1, MEM8.2
unnamed: J4.2, MEM7.2
unnamed: J4.3, MEM6.2
unnamed: J4.4, MEM5.2
unnamed: J4.5, MEM4.2
unnamed: J4.6, MEM3.2
unnamed: J4.7, MEM2.2
unnamed: J4.8, MEM1.2

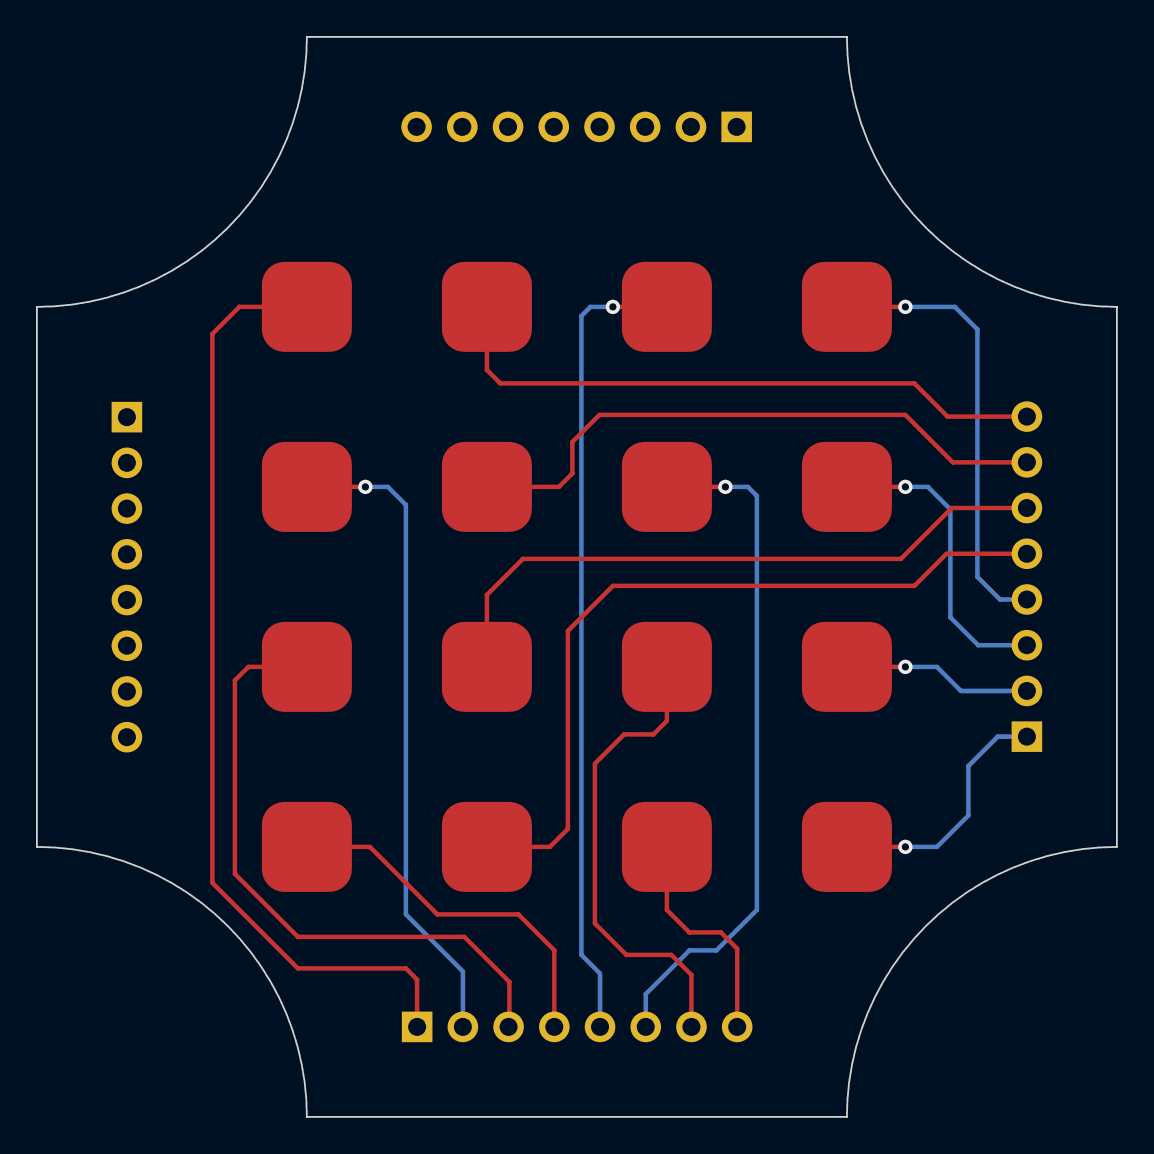
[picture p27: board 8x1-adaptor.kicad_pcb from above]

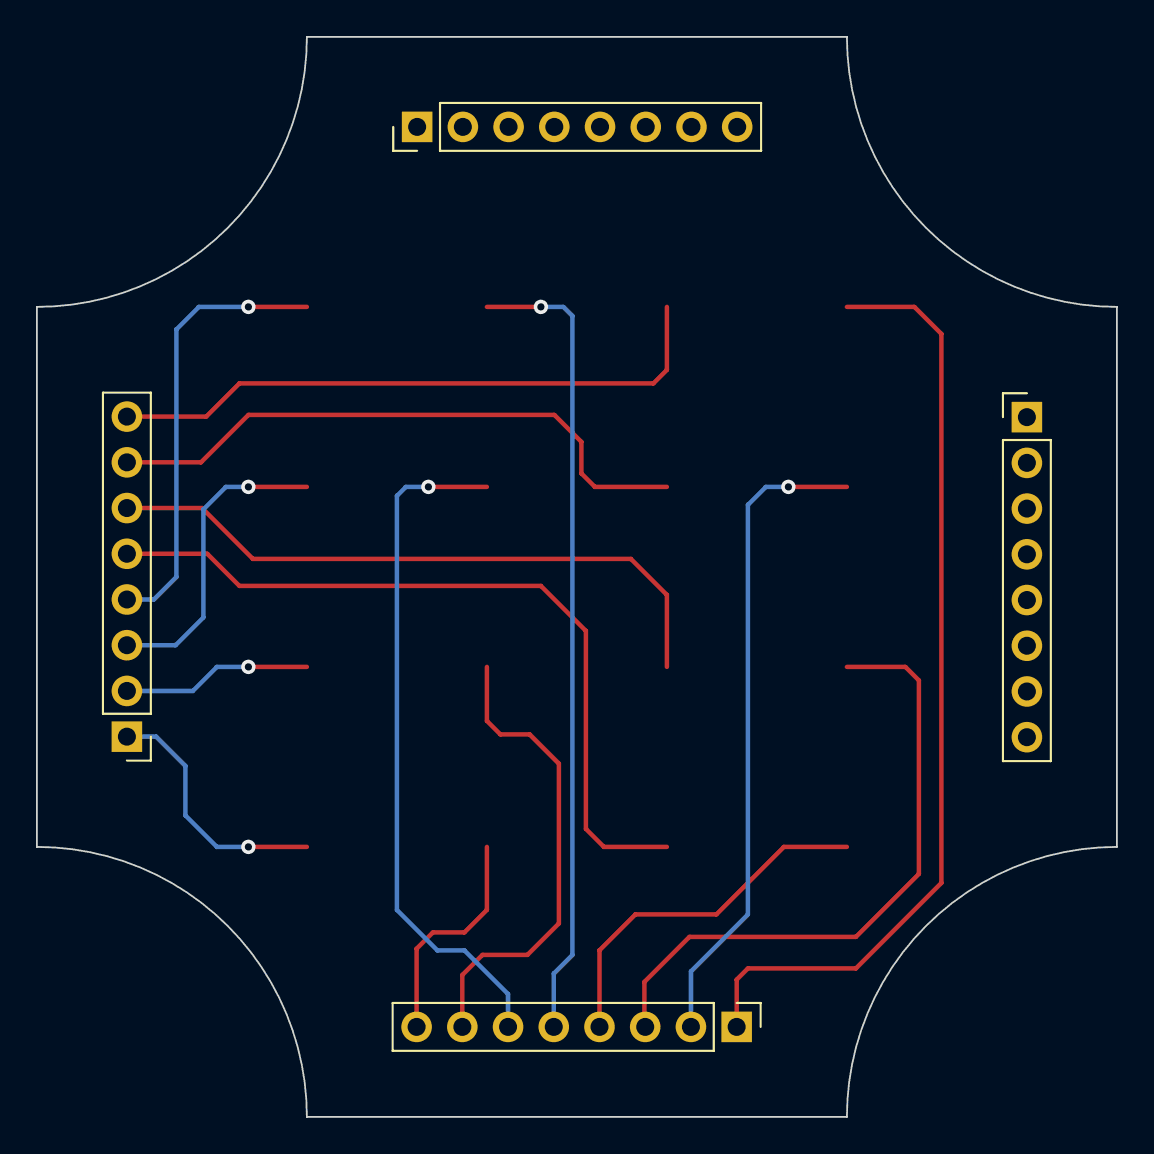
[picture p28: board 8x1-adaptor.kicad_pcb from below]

Board: 2 copper layers, 60.0 x 60.0 mm, 12 parts (4 on the bottom side), 16 nets.

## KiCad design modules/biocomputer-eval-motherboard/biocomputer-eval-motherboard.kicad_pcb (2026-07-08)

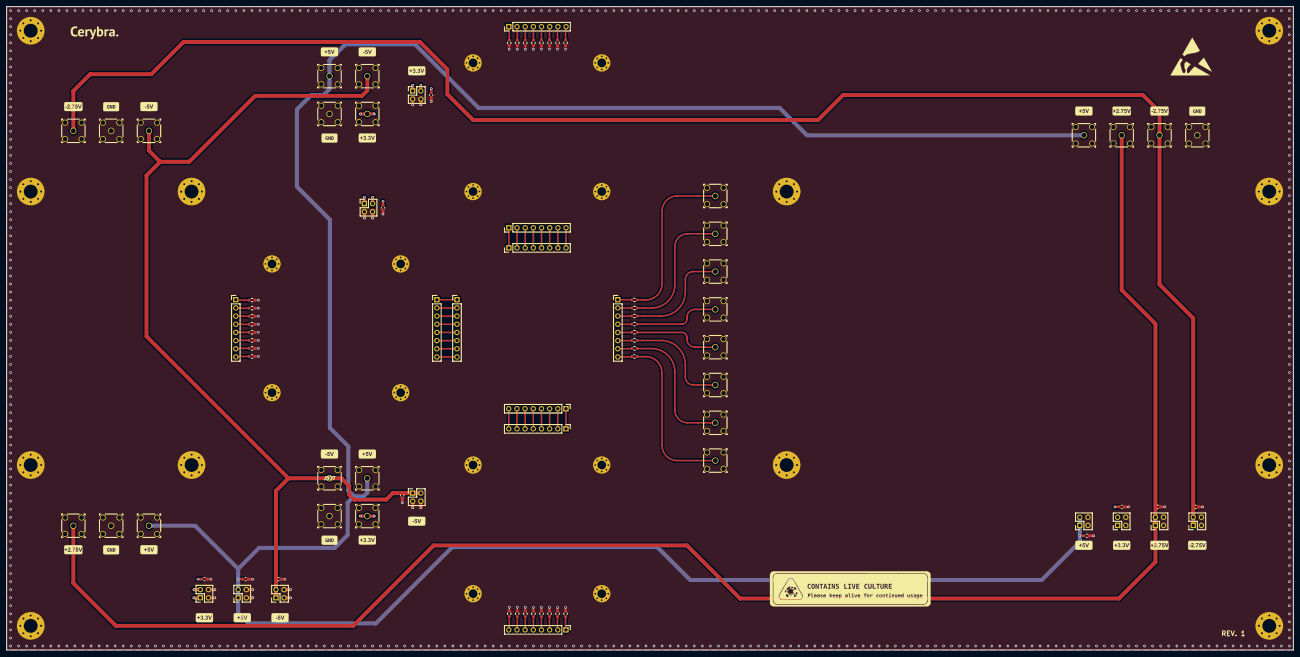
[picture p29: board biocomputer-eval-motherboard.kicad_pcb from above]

Board: 4 copper layers, 400.0 x 200.0 mm, 113 parts (0 on the bottom side), 62 nets.

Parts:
C301, C302, C303, C304, C401, C501, C601, C602, C603, C604: 100nF; C_0603_1608Metric
H101, H102, H103, H104, H201, H202, H203, H204, H601, H602, H603, H604: MountingHole_Pad; MountingHole_4.3mm_M4_Pad_Via
H301, H302, H303, H304, H401, H402, H403, H404, H501, H502, H503, H504: MountingHole_Pad; MountingHole_2.7mm_M2.5_Pad_Via
J101, J102, J103, J104, J105, J106, J107, J108, J201, J202, J203, J204, J205, J206, J305, J306, J307, J308, J311, J312, J313, J314, J605, J606, J607, J608: Conn_Coaxial; CONN_RF2-04A-T-00-50-G_ADM
J109, J110, J111, J112, J309, J310, J402, J403, J502, J503: Conn_01x08; PinHeader_1x08_P2.54mm_Vertical
J113: Traces; TRACES
J301, J302, J303, J304, J401, J501, J601, J602, J603, J604: Conn_01x04; PinHeader_2x02_P2.54mm_Vertical
R101, R102, R103, R104, R105, R106, R107, R108, R301, R302, R303, R304, R305, R306, R307, R308, R401, R402, R403, R404, R405, R406, R407, R408, R501, R502, R503, R504, R505, R506, R507, R508: 10k; R_0603_1608Metric

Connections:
+2V5: C603.2, J203.1 (In), J603.1, J603.2, J606.1 (In)
+3V3: C301.2, C401.2, C501.2, C602.2, J301.1, J301.2, J305.1 (In), J311.1 (In), J401.1, J401.2, J501.1, J501.2, J602.1, J602.2
+5V: C302.2, C601.2, J201.1 (In), J302.1, J302.2, J306.1 (In), J312.1 (In), J601.1, J601.2, J605.1 (In)
-2V5: C604.2, J206.1 (In), J604.1, J604.2, J607.1 (In)
-5V: C303.2, C304.2, J204.1 (In), J303.1, J303.2, J304.1, J304.2, J307.1 (In), J313.1 (In)
/column-selector/COLUMN_SELECT_0: J111.1, J502.1
/column-selector/COLUMN_SELECT_1: J111.2, J502.2
/column-selector/COLUMN_SELECT_2: J111.3, J502.3
/column-selector/COLUMN_SELECT_3: J111.4, J502.4
/column-selector/COLUMN_SELECT_4: J111.5, J502.5
/column-selector/COLUMN_SELECT_5: J111.6, J502.6
/column-selector/COLUMN_SELECT_6: J111.7, J502.7
/column-selector/COLUMN_SELECT_7: J111.8, J502.8
/crossbar/CROSSBAR_OUT_0: J112.1, R101.1
/crossbar/CROSSBAR_OUT_1: J112.2, R102.1
/crossbar/CROSSBAR_OUT_2: J112.3, R103.1
/crossbar/CROSSBAR_OUT_3: J112.4, R104.1
/crossbar/CROSSBAR_OUT_4: J112.5, R105.1
/crossbar/CROSSBAR_OUT_5: J112.6, R106.1
/crossbar/CROSSBAR_OUT_6: J112.7, R107.1
/crossbar/CROSSBAR_OUT_7: J112.8, R108.1
/crossbar/DAC_INPUT_0: J109.1, J309.1
/crossbar/DAC_INPUT_1: J109.2, J309.2
/crossbar/DAC_INPUT_2: J109.3, J309.3
/crossbar/DAC_INPUT_3: J109.4, J309.4
/crossbar/DAC_INPUT_4: J109.5, J309.5
/crossbar/DAC_INPUT_5: J109.6, J309.6
/crossbar/DAC_INPUT_6: J109.7, J309.7
/crossbar/DAC_INPUT_7: J109.8, J309.8
/crossbar/ROW_SELECT_0: J110.1, J402.1
/crossbar/ROW_SELECT_1: J110.2, J402.2
/crossbar/ROW_SELECT_2: J110.3, J402.3
/crossbar/ROW_SELECT_3: J110.4, J402.4
/crossbar/ROW_SELECT_4: J110.5, J402.5
/crossbar/ROW_SELECT_5: J110.6, J402.6
/crossbar/ROW_SELECT_6: J110.7, J402.7
/crossbar/ROW_SELECT_7: J110.8, J402.8
Earth: C301.1, C302.1, C303.1, C304.1, C401.1, C501.1, C601.1, C602.1, C603.1, C604.1, H101.1, H102.1, H103.1, H104.1, H201.1, H202.1, H203.1, H204.1, H301.1, H302.1, H303.1, H304.1, H401.1, H402.1, H403.1, H404.1, H501.1, H502.1, H503.1, H504.1, H601.1, H602.1, H603.1, H604.1, J101.2 (Ext), J102.2 (Ext), J103.2 (Ext), J104.2 (Ext), J105.2 (Ext), J106.2 (Ext), J107.2 (Ext), J108.2 (Ext), J201.2 (Ext), J202.1 (In), J202.2 (Ext), J203.2 (Ext), J204.2 (Ext), J205.1 (In), J205.2 (Ext), J206.2 (Ext), J301.3, J301.4, J302.3, J302.4, J303.3, J303.4, J304.3, J304.4, J305.2 (Ext), J306.2 (Ext), J307.2 (Ext), J308.1 (In), J308.2 (Ext), J311.2 (Ext), J312.2 (Ext), J313.2 (Ext), J314.1 (In), J314.2 (Ext), J401.3, J401.4, J501.3, J501.4, J601.3, J601.4, J602.3, J602.4, J603.3, J603.4, J604.3, J604.4, J605.2 (Ext), J606.2 (Ext), J607.2 (Ext), J608.1 (In), J608.2 (Ext), R301.2, R302.2, R303.2, R304.2, R305.2, R306.2, R307.2, R308.2, R401.2, R402.2, R403.2, R404.2, R405.2, R406.2, R407.2, R408.2, R501.2, R502.2, R503.2, R504.2, R505.2, R506.2, R507.2, R508.2
unnamed: J310.1, R301.1
unnamed: J310.2, R302.1
unnamed: J310.3, R303.1
unnamed: J310.4, R304.1
unnamed: J310.5, R305.1
unnamed: J310.6, R306.1
unnamed: J310.7, R307.1
unnamed: J310.8, R308.1
unnamed: J403.1, R401.1
unnamed: J403.2, R402.1
unnamed: J403.3, R403.1
unnamed: J403.4, R404.1
unnamed: J403.5, R405.1
unnamed: J403.6, R406.1
unnamed: J403.7, R407.1
unnamed: J403.8, R408.1
unnamed: J503.1, R501.1
unnamed: J503.2, R502.1
unnamed: J503.3, R503.1
unnamed: J503.4, R504.1
unnamed: J503.5, R505.1
unnamed: J503.6, R506.1
unnamed: J503.7, R507.1
unnamed: J503.8, R508.1

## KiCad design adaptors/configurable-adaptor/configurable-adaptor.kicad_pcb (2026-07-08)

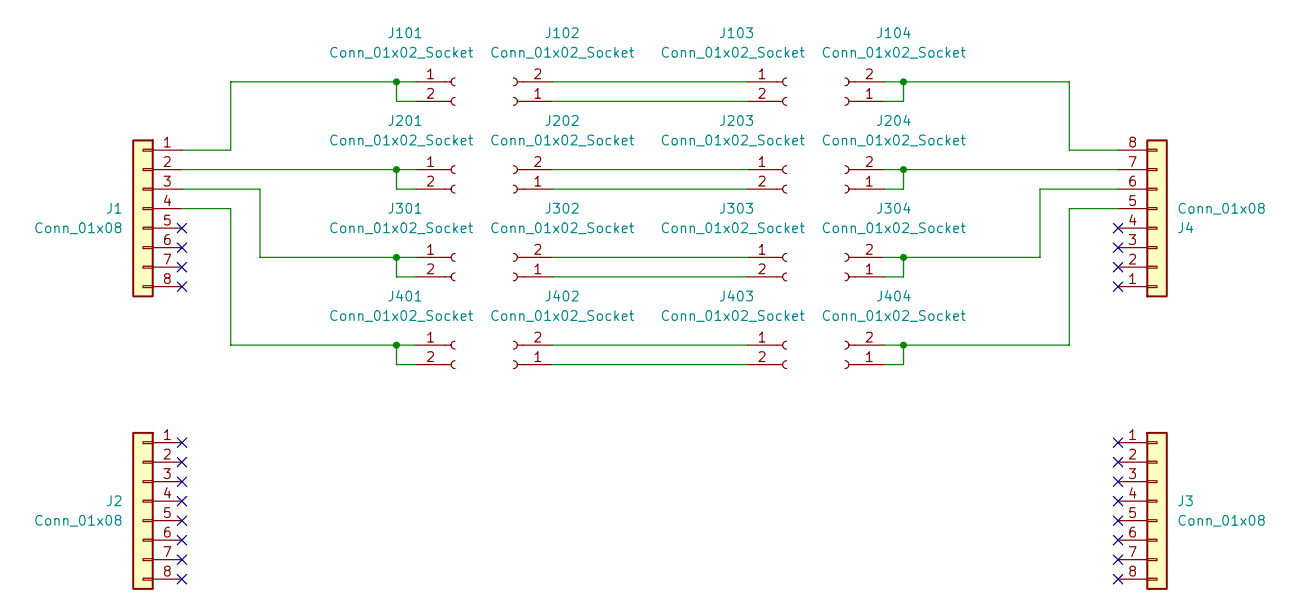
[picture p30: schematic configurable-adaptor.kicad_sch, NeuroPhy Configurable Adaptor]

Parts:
J1, J2, J3, J4: Conn_01x08; PinHeader_1x08_P2.54mm_Vertical
J101, J102, J103, J104, J201, J202, J203, J204, J301, J302, J303, J304, J401, J402, J403, J404: Conn_01x02_Socket; PinSocket_1x02_P2.54mm_Vertical

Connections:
unnamed: J1.1, J101.1, J101.2
unnamed: J1.2, J201.1, J201.2
unnamed: J1.3, J301.1, J301.2
unnamed: J1.4, J401.1, J401.2
unnamed: J4.5, J404.1, J404.2
unnamed: J102.1, J103.2
unnamed: J102.2, J103.1
unnamed: J4.8, J104.1, J104.2
unnamed: J202.1, J203.2
unnamed: J202.2, J203.1
unnamed: J4.7, J204.1, J204.2
unnamed: J302.1, J303.2
unnamed: J302.2, J303.1
unnamed: J4.6, J304.1, J304.2
unnamed: J402.1, J403.2
unnamed: J402.2, J403.1

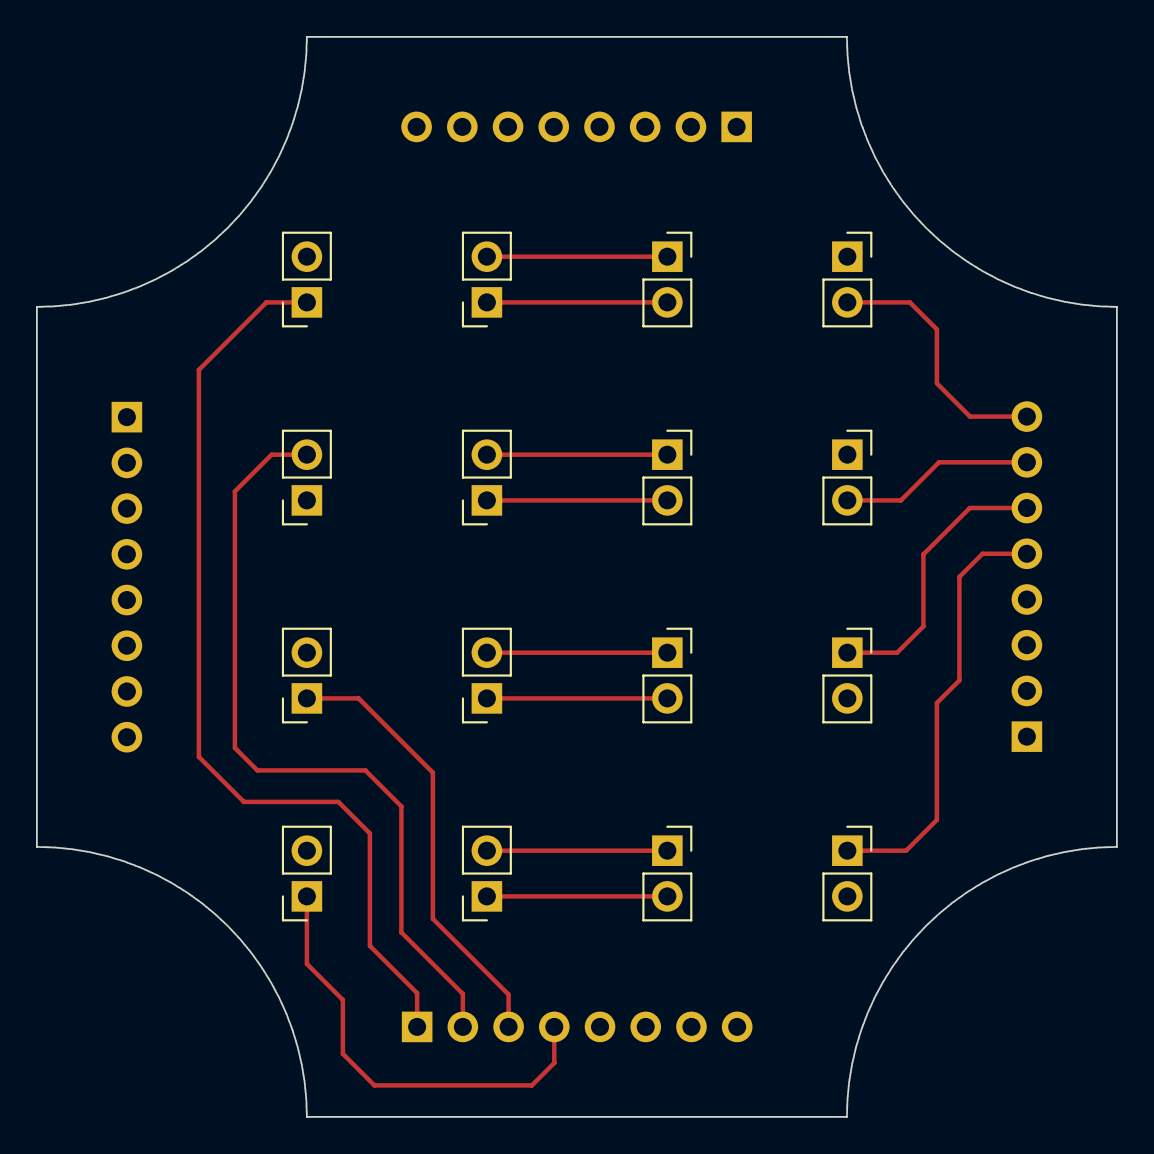
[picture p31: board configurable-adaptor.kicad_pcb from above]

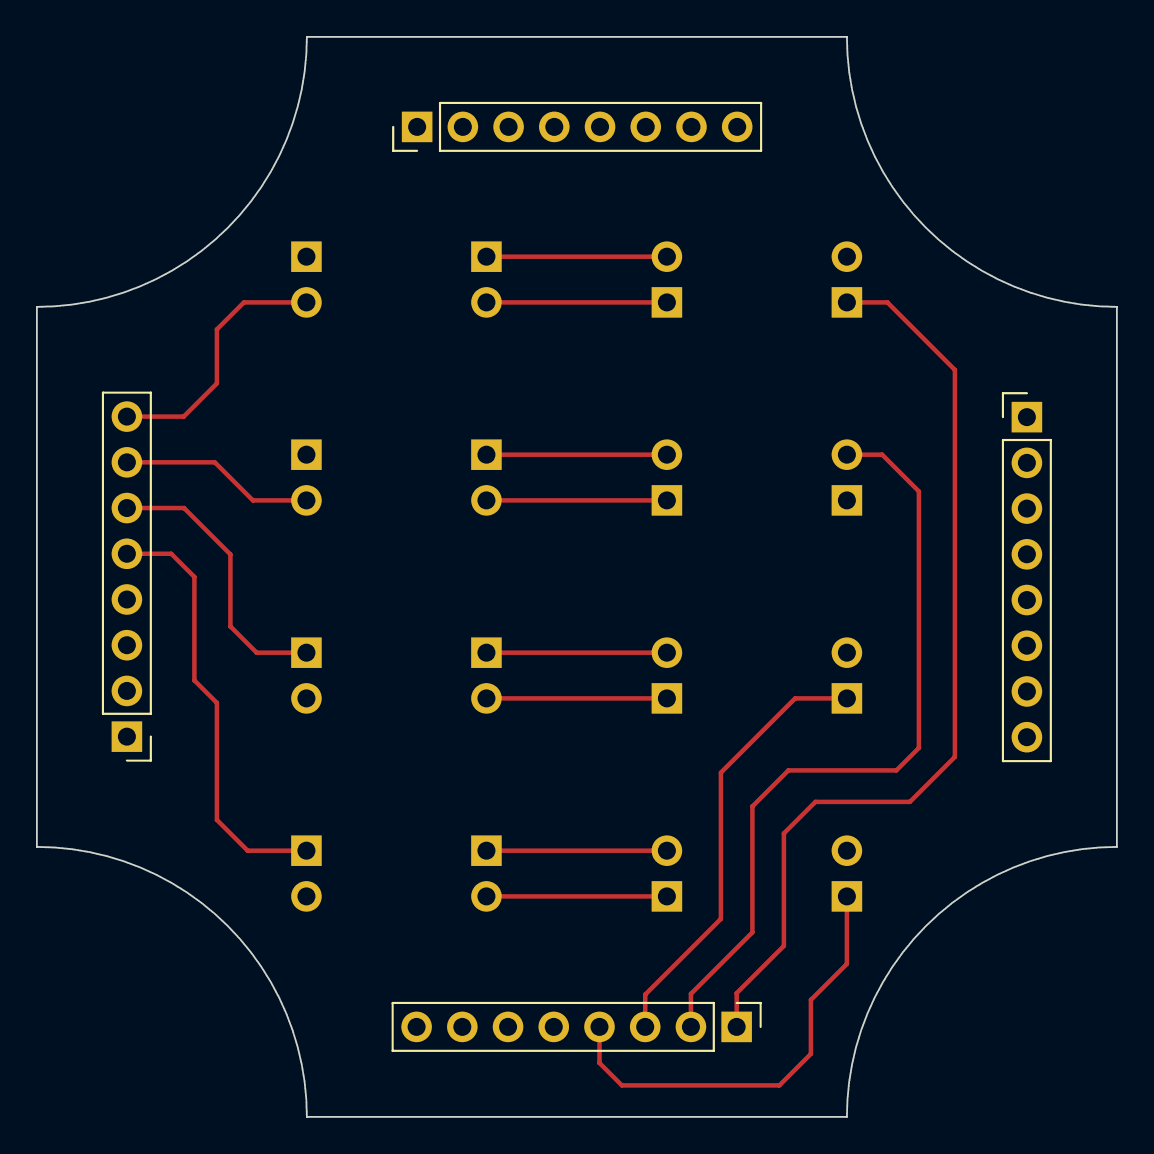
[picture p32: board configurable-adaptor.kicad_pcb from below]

Board: 2 copper layers, 60.0 x 60.0 mm, 20 parts (4 on the bottom side), 16 nets.

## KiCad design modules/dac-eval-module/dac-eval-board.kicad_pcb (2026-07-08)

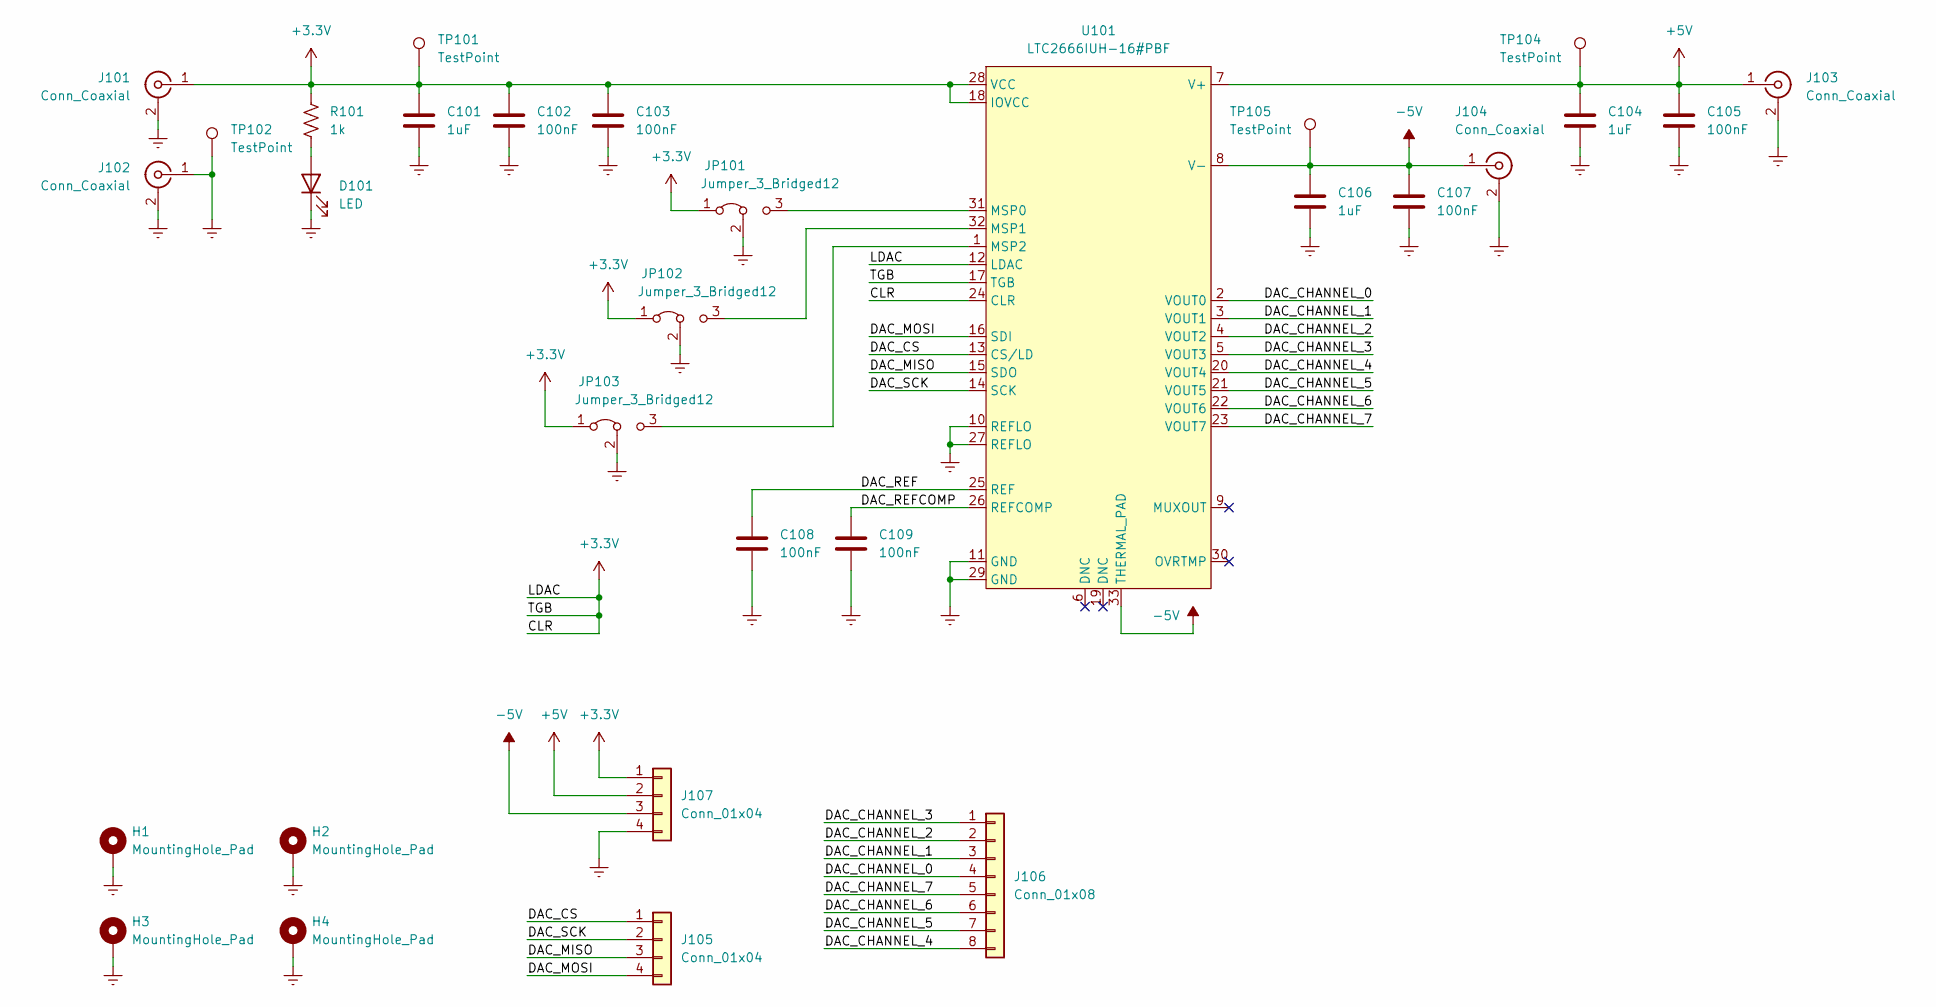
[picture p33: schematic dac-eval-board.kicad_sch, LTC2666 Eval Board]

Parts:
C101, C104, C106: 1uF; C_0402_1005Metric
C102, C103, C105, C107, C108, C109: 100nF; C_0402_1005Metric
D101: LED; LED_0603_1608Metric
H1, H2, H3, H4: MountingHole_Pad; MountingHole_2.7mm_Pad_Via
J101, J102, J103, J104: Conn_Coaxial; CONN_RF2-04A-T-00-50-G_ADM
J105, J107: Conn_01x04; PinHeader_1x04_P2.54mm_Vertical
J106: Conn_01x08; PinHeader_1x08_P2.54mm_Vertical
JP101, JP102, JP103: Jumper_3_Bridged12; PinHeader_1x03_P2.54mm_Vertical
R101: 1k; R_0603_1608Metric
TP101, TP104, TP105: TestPoint; KEYSTONE_5000
TP102: TestPoint; KEYSTONE_5001
U101: LTC2666IUH-16#PBF; QFN-32-1EP_5x5mm_P0.5mm_EP3.45x3.45mm

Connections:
+3.3V: C101.1, C102.1, C103.1, J101.1 (In), J107.1, JP101.1 (A), JP102.1 (A), JP103.1 (A), R101.1, TP101.1, U101.12 (LDAC), U101.17 (TGB), U101.18 (IOVCC), U101.24 (CLR), U101.28 (VCC)
+5V: C104.1, C105.1, J103.1 (In), J107.2, TP104.1, U101.7 (V+)
-5V: C106.1, C107.1, J104.1 (In), J107.3, TP105.1, U101.8 (V-), U101.33 (THERMAL_PAD)
/DAC_CHANNEL_0: J106.4, U101.2 (VOUT0)
/DAC_CHANNEL_1: J106.3, U101.3 (VOUT1)
/DAC_CHANNEL_2: J106.2, U101.4 (VOUT2)
/DAC_CHANNEL_3: J106.1, U101.5 (VOUT3)
/DAC_CHANNEL_4: J106.8, U101.20 (VOUT4)
/DAC_CHANNEL_5: J106.7, U101.21 (VOUT5)
/DAC_CHANNEL_6: J106.6, U101.22 (VOUT6)
/DAC_CHANNEL_7: J106.5, U101.23 (VOUT7)
/DAC_CS: J105.1, U101.13 (CS/LD)
/DAC_MISO: J105.3, U101.15 (SDO)
/DAC_MOSI: J105.4, U101.16 (SDI)
/DAC_REF: C108.1, U101.25 (REF)
/DAC_REFCOMP: C109.1, U101.26 (REFCOMP)
/DAC_SCK: J105.2, U101.14 (SCK)
Earth: C101.2, C102.2, C103.2, C104.2, C105.2, C106.2, C107.2, C108.2, C109.2, D101.1 (K), H1.1, H2.1, H3.1, H4.1, J101.2 (Ext), J102.1 (In), J102.2 (Ext), J103.2 (Ext), J104.2 (Ext), J107.4, JP101.2 (C), JP102.2 (C), JP103.2 (C), TP102.1, U101.10 (REFLO), U101.11 (GND), U101.27 (REFLO), U101.29 (GND)
unnamed: D101.2 (A), R101.2
unnamed: JP101.3 (B), U101.31 (MSP0)
unnamed: JP102.3 (B), U101.32 (MSP1)
unnamed: JP103.3 (B), U101.1 (MSP2)

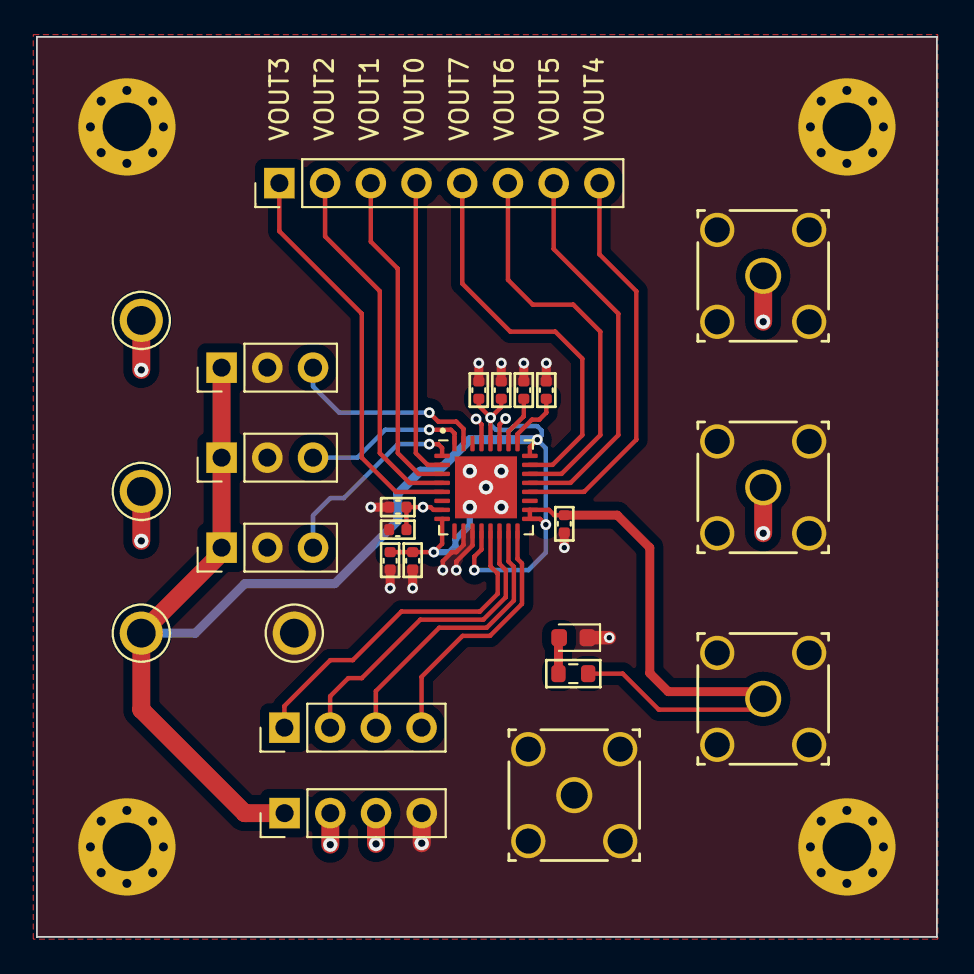
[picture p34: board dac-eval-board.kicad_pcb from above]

Board: 6 copper layers, 50.0 x 50.0 mm, 30 parts (0 on the bottom side), 22 nets.

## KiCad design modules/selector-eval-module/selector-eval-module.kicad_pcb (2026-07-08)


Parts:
C1, C2: 100nF; C_0402_1005Metric
H1, H2, H3, H4: MountingHole_Pad; MountingHole_2.7mm_Pad_Via
J1, J2: Conn_01x08; PinSocket_1x08_P2.54mm_Vertical
J3, J4: Conn_01x04; PinHeader_2x02_P2.54mm_Vertical
JP1: Jumper_3_Bridged12; PinHeader_1x03_P2.54mm_Vertical
TP1, TP2, TP3, TP4, TP5, TP6, TP7, TP8, TP9, TP10, TP11, TP12, TP13, TP14, TP15, TP16: TestPoint; KEYSTONE_5002
TP18: TestPoint; KEYSTONE_5000
TP19: TestPoint; KEYSTONE_5006
U1: MAX14662ETI+T; TQFN-28-EP1_4.00x4.00mm_P5.0mm

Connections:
/+3.3V: C1.1, J4.1, J4.2, JP1.1 (A), TP18.1, U1.22 (SD), U1.26 (VCC)
/A1: J1.1, TP1.1, U1.2 (A1)
/A2: J1.2, TP2.1, U1.3 (A2)
/A3: J1.3, TP3.1, U1.4 (A3)
/A4: J1.4, TP4.1, U1.5 (A4)
/A5: J1.5, TP5.1, U1.6 (A5)
/A6: J1.6, TP6.1, U1.7 (A6)
/A7: J1.7, TP7.1, U1.8 (A7)
/A8: J1.8, TP8.1, U1.9 (A8)
/B1: J2.1, TP9.1, U1.21 (B1)
/B2: J2.2, TP10.1, U1.20 (B2)
/B3: J2.3, TP11.1, U1.19 (B3)
/B4: J2.4, TP12.1, U1.18 (B4)
/B5: J2.5, TP13.1, U1.17 (B5)
/B6: J2.6, TP14.1, U1.16 (B6)
/B7: J2.7, TP15.1, U1.15 (B7)
/B8: J2.8, TP16.1, U1.14 (B8)
/CLK: J3.3, U1.24 (SCLK/SCL)
/CS: J3.4, U1.23 (CS/AD0)
/MISO: J3.1, U1.28 (DOUT/AD1)
/MOSI: J3.2, U1.27 (DIN/SDA)
/SPI/I2C_SELECT: C2.1, JP1.2 (C), U1.1 (SPI/I2C)
Earth: C1.2, C2.2, H1.1, H2.1, H3.1, H4.1, J4.3, J4.4, JP1.3 (B), TP19.1, U1.11 (GND), U1.25 (GND)

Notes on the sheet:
MAX14662 8xSPST SWITCH
TESTPOINTS


Board: 4 copper layers, 50.0 x 50.0 mm, 30 parts (0 on the bottom side), 23 nets.

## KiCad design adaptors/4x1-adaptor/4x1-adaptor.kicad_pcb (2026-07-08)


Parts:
J1, J2, J3, J4: Conn_01x08; PinHeader_1x08_P2.54mm_Vertical
MEM1, MEM2, MEM3, MEM4: NeuroPhy_Memristor_5x5mm

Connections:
unnamed: J1.1, MEM1.1
unnamed: J1.3, MEM2.1
unnamed: J1.6, MEM3.1
unnamed: J1.8, MEM4.1
unnamed: J4.1, MEM4.2
unnamed: J4.3, MEM3.2
unnamed: J4.6, MEM2.2
unnamed: J4.8, MEM1.2



Board: 2 copper layers, 60.0 x 60.0 mm, 8 parts (4 on the bottom side), 8 nets.

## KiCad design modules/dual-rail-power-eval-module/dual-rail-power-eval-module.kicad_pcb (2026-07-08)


Board: 4 copper layers, 65.0 x 100.0 mm, 81 parts (0 on the bottom side), 25 nets.

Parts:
C1, C2, C15, C16, C23, C24: 10uF; C_0805_2012Metric
C3: 1uF; C_0402_1005Metric
C4: 4.7uF; C_0402_1005Metric
C5, C6: 22uF; C_0805_2012Metric
C7, C8: 100uF; C_0805_2012Metric
C9, C10, C11, C12, C17, C18, C19, C20: 10nF; C_0402_1005Metric
C13, C14, C21, C22: 100nF; C_0402_1005Metric
H1, H2, H3, H4: MountingHole_Pad; MountingHole_4.3mm_M4_Pad_Via
J1, J2, J3, J4, J5, J6, J7, J8, J9, J10: Conn_Coaxial; CONN_RF2-04A-T-00-50-G_ADM
L1, L2: 100uH; L_0805_2012Metric
R1, R3: 221k; R_0402_1005Metric
R2: 68.9k; R_0402_1005Metric
R4: 69.8k; R_0402_1005Metric
R5, R6: 1.3; R_0805_2012Metric
R7, R9: 47k; R_0402_1005Metric
R8, R10: 35k7; R_0402_1005Metric
R11, R13: 97k6; R_0402_1005Metric
R12, R14: 30k1; R_0402_1005Metric
TP1, TP2, TP3, TP4, TP5, TP6: TestPoint; KEYSTONE_5000
TP7, TP8, TP9, TP10, TP11, TP12: TestPoint; KEYSTONE_5006
TP13, TP14, TP15, TP16, TP17, TP18, TP19, TP20, TP21, TP22: Turret; TestPoint_Plated_Hole_D2.0mm
U1: LM27762; DSS0012B
U2, U4: TPS7A4901DRBR; VSON-8
U3, U5: TPS7A3001DRBR; VSON-8

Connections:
/+2.75V: C9.1, C13.1, C15.1, J3.1 (In), R7.2, TP3.1, TP16.1, U2.1 (OUT)
/+2.75V_REG_FB: C9.2, R7.1, R8.2, U2.2 (FB)
/+2.75V_REG_NR/SS: C10.1, U2.6 (NR/SS)
/+3.3V: C1.1, C2.1, TP13.1, TP17.1, U1.3 (VIN), U1.8 (EN-), U1.12 (EN+)
/+5.5V: C7.1, J1.1 (In), L1.2, TP1.1, TP14.1, U2.5 (EN), U2.8 (IN), U4.5 (EN), U4.8 (IN)
/+5V: C17.1, C21.1, C23.1, J5.1 (In), R11.2, TP5.1, TP15.1, U4.1 (OUT)
/+5V_REG_FB: C17.2, R11.1, R12.2, U4.2 (FB)
/+5V_REG_NR/SS: C18.1, U4.6 (NR/SS)
/-2.75V: C11.1, C14.1, C16.1, J4.1 (In), R9.2, TP4.1, TP20.1, U3.1 (OUT)
/-2.75V_REG_FB: C11.2, R9.1, R10.2, U3.2 (FB)
/-2.75V_REG_NR/SS: C12.1, U3.6 (NR/SS)
/-5.5V: C8.1, J2.1 (In), L2.2, TP2.1, TP18.1, U3.5 (EN), U3.8 (IN), U5.5 (EN), U5.8 (IN)
/-5V: C19.1, C22.1, C24.1, J6.1 (In), R13.2, TP6.1, TP19.1, U5.1 (OUT)
/-5V_REG_FB: C19.2, R13.1, R14.2, U5.2 (FB)
/-5V_REG_NR/SS: C20.1, U5.6 (NR/SS)
/C1+: C3.2, U1.10 (C1+)
/C1-: C3.1, U1.9 (C1-)
/CP_CAP: C4.1, U1.5 (CP)
/CP_NEG_FB: R3.1, R4.2, U1.7 (FB-)
/CP_NEG_OUT: C6.1, R3.2, R6.2, U1.6 (OUT-)
/CP_POS_FB: R1.1, R2.2, U1.2 (FB+)
/CP_POS_OUT: C5.1, R1.2, R5.2, U1.11 (OUT+)
Earth: C1.2, C2.2, C4.2, C5.2, C6.2, C7.2, C8.2, C10.2, C12.2, C13.2, C14.2, C15.2, C16.2, C18.2, C20.2, C21.2, C22.2, C23.2, C24.2, H1.1, H2.1, H3.1, H4.1, J1.2 (Ext), J2.2 (Ext), J3.2 (Ext), J4.2 (Ext), J5.2 (Ext), J6.2 (Ext), J7.1 (In), J7.2 (Ext), J8.1 (In), J8.2 (Ext), J9.1 (In), J9.2 (Ext), J10.1 (In), J10.2 (Ext), R2.1, R4.1, R8.1, R10.1, R12.1, R14.1, TP7.1, TP8.1, TP9.1, TP10.1, TP11.1, TP12.1, TP21.1, TP22.1, U1.1 (PGOOD), U1.4 (GND), U1.13 (GND), U2.4 (GND), U2.9 (EP), U2.10 (EP), U2.11 (EP), U2.12 (EP), U2.13 (EP), U3.4 (GND), U3.9 (EP), U3.10 (EP), U3.11 (EP), U3.12 (EP), U3.13 (EP), U4.4 (GND), U4.9 (EP), U4.10 (EP), U4.11 (EP), U4.12 (EP), U4.13 (EP), U5.4 (GND), U5.9 (EP), U5.10 (EP), U5.11 (EP), U5.12 (EP), U5.13 (EP)
unnamed: L1.1, R5.1
unnamed: L2.1, R6.1

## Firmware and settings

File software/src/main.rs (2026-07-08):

#![no_std]
#![no_main]

mod datasets;
mod drivers;
mod linalg;
mod random;

use core::f32::consts::PI;
use core::fmt::Write;

use libm::{exp, fabsf, floorf, sin, sqrtf};

use panic_halt as _;

use cortex_m_semihosting::hprintln;

use embedded_hal::blocking::spi::WriteIter;
use embedded_hal::serial::{Read as ReadSerial, Write as WriteSerial};

use stm32h7xx_hal::{nb, prelude::*, serial::Error, spi};

use stm32h7xx_hal::rng::RngCore;

use crate::drivers::adc::{ParallelBus, ParallelBusConfig, ADC};
use crate::drivers::dac::DAC;

use crate::linalg::{Array, Dot, Vector};

use crate::random::distribution::Gaussian;
use crate::random::generator::{Generator, XORShift32};

const SEED: u32 = 237643274;

// NOTE: There is a bug where this hangs exactly at 1204.
const STEPS: usize = 1200;
const SPLIT: usize = 1000;

const HORIZON: usize = 5;

const PHYSICAL_NODES: usize = 8;
const VIRTUAL_NODES: usize = 4;

const STATES: usize = 2 * VIRTUAL_NODES * PHYSICAL_NODES;
const DIMENSION: usize = STATES + 4;

#[link_section = ".axisram"]
// The last 32 are reservoir recordings, while the first four are the coordinates and target, respectively.
static mut RECORDINGS: [[f32; DIMENSION]; STEPS] = [[0.0; DIMENSION]; STEPS];

pub type VanDerPolDataset<const N: usize> = [(f32, f32, f32); N];
pub type RabinovichFabrikant<const N: usize> = [(f32, f32, f32); N];
pub type Rossler<const N: usize> = [(f32, f32, f32); N];

pub fn van_der_pol<const N: usize>(mu: f32, dt: f32) -> impl Iterator<Item = (f32, f32, f32)> {
    let (mut x, mut y): (f32, f32) = (1.0, 0.0);

    (0..N).into_iter().map(move |t| {
        let phase = (t as f32 / (N as f32 - 1.0)) * 15.0 * PI;
        let force = 0.5 * libm::sinf(phase);

        let point = (x, y, force);

        let dx_dt = y;
        let dy_dt = mu * (1.0 - (x * x)) * y - x + force;

        x += dx_dt * dt;
        y += dy_dt * dt;

        point
    })
}

pub fn rabinovich_fabrikant<const N: usize>(alpha: f32, gamma: f32, dt: f32) -> impl Iterator<Item = (f32, f32, f32)> {
    let (mut x, mut y, mut z) = (-1.0, 0.0, 0.5);

    (0..N).into_iter().map(move |t| {
        let point = (x, y, z);

        let dx_dt = y * (z - 1.0 + (x * x)) + gamma * x;
        let dy_dt = x * (3.0 * z + 1.0 - (x * x)) + gamma * y;
        let dz_dt = -2.0 * z * (alpha + x * y);

        x += dx_dt * dt;
        y += dy_dt * dt;
        z += dz_dt * dt;

        point
    })
}

pub fn rossler<const N: usize>(a: f32, b: f32, c: f32, dt: f32) -> impl Iterator<Item = (f32, f32, f32)> {
    // a, b, c = 0.2, 0.2, 5.7.
    let (mut x, mut y, mut z) = (0.1, 0.0, 0.0);

    (0..N).into_iter().map(move |t| {
        let point = (x, y, z);

        let dx_dt = -y - z;
        let dy_dt = x + (a * y);
        let dz_dt = b + (z * (x - c));

        x += dx_dt * dt;
        y += dy_dt * dt;
        z += dz_dt * dt;

        point
    })
}

pub fn train<const S: usize, const N: usize>(
    recordings: &[[f32; S]],
    readout: &mut Vector<N>,
    lr: f32,
    baseline: bool,
) {
    for t in 0..recordings.len() {
        let (points, target) = ((recordings[t][0], recordings[t][2]), recordings[t][3]);

        let state: Vector<N> = if baseline {
            let mut s = [0.0; N];
            if N >= 2 {
                s[0] = points.0;
                s[1] = points.1;
            }
            Vector::from(s)
        } else {
            let mut s = [0.0; N];
            s.copy_from_slice(&recordings[t][(S - N)..]);

            Vector::from(s)
        };

        let error = target - state.dot(&mut *readout);

        *readout = *readout + (state * (lr * error));
    }
}

pub fn test<const S: usize, const N: usize>(
    recordings: &[[f32; S]],
    readout: &Vector<N>,
    baseline: bool,
) -> f32 {
    let mut errors = 0.0;

    for t in 0..recordings.len() {
        let (points, target) = ((recordings[t][0], recordings[t][2]), recordings[t][3]);

        let state: Vector<N> = if baseline {
            let mut s = [0.0; N];
            if N >= 2 {
                s[0] = points.0;
                s[1] = points.1;
            }
            Vector::from(s)
        } else {
            let mut s = [0.0; N];
            s.copy_from_slice(&recordings[t][(S - N)..]);

            Vector::from(s)
        };

        errors += libm::powf(state.dot(readout) - target, 2.0);
    }

    errors / (recordings.len() as f32)
}

#[cortex_m_rt::entry]
fn main() -> ! {
    hprintln!("Initialized...");

    // Get access to the core peripherals.
    let mut core = cortex_m::Peripherals::take().unwrap();

    // Get access to the device specific peripherals from the peripheral access crate.
    let dp = stm32h7xx_hal::stm32::Peripherals::take().unwrap();

    // Take ownership over the RCC devices and convert them into the corresponding HAL structs.
    let rcc = dp.RCC.constrain();

    let pwr = dp.PWR.constrain();
    let pwrcfg = pwr.freeze();

    // Freeze the configuration of all the clocks in the system and
    // retrieve the Core Clock Distribution and Reset (CCDR) object.
    let rcc = rcc.sys_ck(400.MHz()).use_hse(8.MHz()).bypass_hse();
    let ccdr = rcc.freeze(pwrcfg, &dp.SYSCFG);

    let mut delay = core.SYST.delay(ccdr.clocks);

    // Acquire the GPIO peripherals.
    let gpio_a = dp.GPIOA.split(ccdr.peripheral.GPIOA);
    let gpio_b = dp.GPIOB.split(ccdr.peripheral.GPIOB);
    let gpio_d = dp.GPIOD.split(ccdr.peripheral.GPIOD);
    let gpio_e = dp.GPIOE.split(ccdr.peripheral.GPIOE);
    let gpio_f = dp.GPIOF.split(ccdr.peripheral.GPIOF);

    // Configuring the pins for the ADC parallel interface.
    let config = ParallelBusConfig {
        db0: gpio_e.pe3.into_pull_down_input(),
        db1: gpio_b.pb1.into_pull_down_input(),
        db2: gpio_b.pb2.into_pull_down_input(),
        db3: gpio_b.pb3.into_pull_down_input(),
        db4: gpio_b.pb4.into_pull_down_input(),
        db5: gpio_b.pb5.into_pull_down_input(),
        db6: gpio_b.pb6.into_pull_down_input(),
        db7: gpio_b.pb7.into_pull_down_input(),
        db8: gpio_b.pb8.into_pull_down_input(),
        db9: gpio_b.pb9.into_pull_down_input(),
        db10: gpio_b.pb10.into_pull_down_input(),
        db11: gpio_b.pb11.into_pull_down_input(),
        db12: gpio_b.pb12.into_pull_down_input(),
        db13: gpio_e.pe4.into_pull_down_input(),
        db14: gpio_e.pe2.into_pull_down_input(),
        db15: gpio_b.pb15.into_pull_down_input(),
    };

    let convst = gpio_d.pd3.into_push_pull_output();

    let eoc = gpio_d.pd4.into_pull_down_input();

    let rd = gpio_d.pd6.into_push_pull_output();
    let wr = gpio_d.pd7.into_push_pull_output();

    let sck = gpio_f.pf7.into_alternate();
    let miso = gpio_f.pf8.into_alternate();
    let mosi = gpio_f.pf9.into_alternate();

    // Initialize required CS pins.
    let dac_cs = gpio_a.pa0.into_push_pull_output();
    let adc_cs = gpio_d.pd5.into_push_pull_output();

    hprintln!("Initializing SPI ... ");

    // Initialize the SPI peripheral.
    let mut spi = dp.SPI5.spi(
        (sck, miso, mosi),
        spi::MODE_0,
        3.MHz(),
        ccdr.peripheral.SPI5,
        &ccdr.clocks,
    );

    // Initialize serial.
    let tx = gpio_d.pd8.into_alternate();
    let rx = gpio_d.pd9.into_alternate();

    let serial = dp
        .USART3
        .serial((tx, rx), 921600.bps(), ccdr.peripheral.USART3, &ccdr.clocks)
        .unwrap();

    let (mut tx, _) = serial.split();

    // Initialize DAC, ADC converters.
    let mut dac = DAC::new(spi, dac_cs, (-2.5, 2.5));
    let mut adc = ADC::new(ParallelBus::new(config), convst, eoc, adc_cs, rd, wr);

    dac.init();
    adc.init();

    dac.zero();

    hprintln!("Starting...");

    // Setup RNG.
    let mut rng = XORShift32(SEED);

    // let mu: f32 = 1.5;
    let (a, b, c): (f32, f32, f32) = (0.2, 0.2, 5.7);
    let dt: f32 = 0.05;

    let pulse: f32 = -0.01;
    let span: (f32, f32) = (-5.0, 5.0);

    // Generate the Van der Pol dataset.
    // let dataset = van_der_pol::<STEPS>(mu, dt);
    let dataset = rossler::<STEPS>(a, b, c, dt);

    let recordings = unsafe { &mut RECORDINGS };

    for (t, (x, y, z)) in dataset.enumerate() {
        recordings[t][0] = x;
        recordings[t][1] = y;
        recordings[t][2] = z;

        for (i, point) in [x, z].iter().enumerate() {
            for v in 0..VIRTUAL_NODES {
                dac.all((pulse * point).clamp(-1.0, 1.0));

                delay.delay_us(100u32);

                adc.sample(&mut delay);

                for channel in 0..PHYSICAL_NODES {
                    let index = 4 + (v * PHYSICAL_NODES) + channel;
                    let offset = i * (VIRTUAL_NODES * PHYSICAL_NODES);

                    recordings[t][index + offset] = adc.channel(channel).voltage(span);
                }
            }
        }
    }

    hprintln!("Training readout...");

    dac.zero();

    // Setup the horizon targets.
    for t in 0..(STEPS - HORIZON) {
        recordings[t][3] = recordings[t + HORIZON][1];
    }

    // Establish reservoir performance.
    let mut readout: [f32; STATES] =
        Gaussian::sample(0.0, 0.1, 1000, &mut rng).expect("Unable to initialized readout weights.");
    let mut readout = Vector::from(readout);

    train::<DIMENSION, STATES>(&recordings[..SPLIT], &mut readout, 0.001, false);
    let reservoir_performance =
        test::<DIMENSION, STATES>(&recordings[SPLIT..(STEPS - HORIZON)], &mut readout, false);

    hprintln!("{:?}", reservoir_performance);

    // Establish baseline performance.
    let mut baseline_readout: [f32; 2] =
        Gaussian::sample(0.0, 0.1, 1000, &mut rng).expect("Unable to initialized readout weights.");
    let mut baseline_readout = Vector::from(baseline_readout);

    train::<DIMENSION, 2>(&recordings[..SPLIT], &mut baseline_readout, 0.001, true);
    let baseline_performance = test::<DIMENSION, 2>(
        &recordings[SPLIT..(STEPS - HORIZON)],
        &mut baseline_readout,
        true,
    );

    hprintln!("{:?}", baseline_performance);

    hprintln!("Transmitting data over serial...");

    // Send a synchronization header to align the Python receiver.
    let sync_word: [u8; 4] = [0x53, 0x59, 0x4E, 0x43];
    for byte in sync_word.iter() {
        nb::block!(tx.write(*byte)).ok();
    }

    unsafe {
        let pointer = RECORDINGS.as_ptr() as *const u8;
        let total_bytes = STEPS * DIMENSION * core::mem::size_of::<f32>();
        let byte_slice = core::slice::from_raw_parts(pointer, total_bytes);

        // cortex_m::asm::dmb();

        for byte in byte_slice.iter() {
            nb::block!(tx.write(*byte)).ok();
        }
    }

    hprintln!("Transmission complete.");

    loop {}
}

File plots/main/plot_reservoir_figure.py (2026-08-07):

import os

import ast

import csv

import numpy as np

import matplotlib
import matplotlib.pyplot as plt

from matplotlib.gridspec import GridSpec
from matplotlib.transforms import ScaledTranslation

from sklearn.linear_model import (
    LinearRegression, LogisticRegression
)
from sklearn.model_selection import train_test_split

from sklearn.metrics import accuracy_score

from typing import Any, Optional


def load_temporal_xor_recordings(file_path: str) -> np.ndarray:
    data = []
    with open(file_path, 'r') as file:
        reader = csv.reader(file, delimiter=',')

        next(reader)
        for row in reader:
            data.append([
                *map(lambda value: ast.literal_eval(value), row)
            ])

    return np.vstack(data)


class Figure6:

    def __init__(
            self,
            figure: plt.Figure,
            **kwargs
    ):
        self.figure = figure

        self.gs = GridSpec(5, 4, figure=figure)

        self.ax_a = figure.add_subplot(self.gs[0:2, 0:2])
        self.ax_b = figure.add_subplot(self.gs[2:3, 0:2])

        self.ax_c = figure.add_subplot(self.gs[0:1, 2:4])
        self.ax_d = figure.add_subplot(self.gs[1:2, 2:4])
        self.ax_e = figure.add_subplot(self.gs[2:3, 2:4])

        self.palette = kwargs.get(
            'palette', {
                'main': '#FFCB05',
                'deep': '#B6862C',
                'error': 'gray',
                'target': 'black'
            }
        )

    @staticmethod
    def plot_temporal_xor(
            steps: np.ndarray,
            series: np.ndarray,
            figure: plt.Figure,
            ax: plt.Axes,
            label: str,
            palette: dict[str, str]
    ) -> None:
        ax.set_facecolor('white')

        ax.set_xlabel('Timesteps', fontsize=6)
        ax.set_ylabel('Value', fontsize=6)

        ax.tick_params(colors='black', labelsize=5, which='both')

        ax.xaxis.set_label_position('bottom')
        ax.xaxis.set_tick_params(
            pad=2,
            labelbottom=True,
            bottom=True,
            labelsize=5,
            labelrotation=0,
            color='black'
        )

        ax.spines[['top', 'right', 'bottom']].set_visible(False)
        ax.spines['left'].set_linewidth(1.0)
        ax.spines['left'].set_color('black')

        ax.step(steps, series, alpha=0.9, color=palette['target'], linewidth=1.5)

        ax.text(
            0.0,
            1.0,
            label,
            transform=(
                    ax.transAxes +
                    ScaledTranslation(-10 / 72, 7 / 72, figure.dpi_scale_trans)
            ),
            fontsize=7,
            fontweight='bold',
            va='bottom',
            ha='right'
        )

    @staticmethod
    def plot_temporal_xor_results(
            steps: np.ndarray,
            baseline: np.ndarray,
            predictions: np.ndarray,
            figure: plt.Figure,
            ax: plt.Axes,
            label: str,
            palette: dict[str, str],
            title: Optional[str] = None
    ) -> None:
        ax.set_facecolor('white')

        if isinstance(title, str):
            ax.set_title(title, fontsize=7)

        ax.set_xlabel('Timesteps', fontsize=6)
        ax.set_ylabel('Value', fontsize=6)

        ax.tick_params(colors='black', labelsize=5, which='both')

        ax.xaxis.set_label_position('bottom')
        ax.xaxis.set_tick_params(
            pad=2,
            labelbottom=True,
            bottom=True,
            labelsize=5,
            labelrotation=0,
            color='black'
        )

        ylims = ax.get_ylim()
        ax.set_yticks([ylims[0], ylims[1]])

        ax.spines[['top', 'right', 'bottom']].set_visible(False)
        ax.spines['left'].set_linewidth(1.0)
        ax.spines['left'].set_color('black')

        ax.step(steps, predictions, alpha=0.9, color=palette['main'], linewidth=1.5)
        ax.step(
            steps,
            baseline,
            color=palette['error'],
            alpha=0.8,
            linewidth=0.75,
            linestyle='--'
        )

        ax.text(
            0.0,
            1.0,
            label,
            transform=(
                    ax.transAxes +
                    ScaledTranslation(-10 / 72, 7 / 72, figure.dpi_scale_trans)
            ),
            fontsize=7,
            fontweight='bold',
            va='bottom',
            ha='right'
        )

    @staticmethod
    def plot_temporal_xor_trial_performances(
            figure: plt.Figure,
            ax: plt.Axes,
            label: str,
            palette: dict[str, str],
    ) -> None:
        ax.set_facecolor('white')

        ax.set_title('Temporal XOR Trials', fontsize=7)

        ax.set_xlabel('Accuracy', fontsize=6)
        ax.set_ylabel('Counts', fontsize=6)

        ax.tick_params(colors='black', labelsize=5, which='both')

        ax.xaxis.set_label_position('bottom')
        ax.xaxis.set_tick_params(
            pad=2,
            labelbottom=True,
            bottom=True,
            labelsize=5,
            labelrotation=0,
            color='black'
        )

        ax.spines[['top', 'right', 'bottom']].set_visible(False)
        ax.spines['left'].set_linewidth(1.0)
        ax.spines['left'].set_color('black')

        # Taken directly from the training results run on the microcontroller.
        ax.hist([
            [0.5017, 0.5017, 0.66, 0.66, 0.66],
            [1.0, 1.0, 1.0, 0.92, 0.93, 0.90]
        ],
            bins=15,
            color=[palette['error'], palette['main']],
            density=True
        )

        ax.text(
            0.0,
            1.0,
            label,
            transform=(
                    ax.transAxes +
                    ScaledTranslation(-10 / 72, 7 / 72, figure.dpi_scale_trans)
            ),
            fontsize=7,
            fontweight='bold',
            va='bottom',
            ha='right'
        )

    @staticmethod
    def plot_ode_prediction(
            x_true: np.ndarray,
            y_true: np.ndarray,
            baseline_predictions: np.ndarray,
            readout_predictions: np.ndarray,
            figure: plt.Figure,
            ax: plt.Axes,
            label: str,
            palette: dict[str, str],
            title: Optional[str] = None
    ) -> None:
        ax.set_facecolor('white')

        if isinstance(title, str):
            ax.set_title(title, fontsize=7)

        ax.set_xlabel('X Coordinate', fontsize=6)
        ax.set_ylabel('Y Coordinate', fontsize=6)

        ax.tick_params(colors='black', labelsize=5, which='both')

        ax.xaxis.set_label_position('bottom')
        ax.xaxis.set_tick_params(
            pad=2,
            labelbottom=True,
            bottom=True,
            labelsize=5,
            labelrotation=0,
            color='black'
        )

        ax.spines[['top', 'right', 'bottom']].set_visible(False)
        ax.spines['left'].set_linewidth(1.0)
        ax.spines['left'].set_color('black')
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

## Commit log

2026-07-08 Initial commit; dumping current data files
    [adc-noise-recordings.csv, device-pulse-recordings.csv, dynamic-pulses-1.csv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]
2026-07-08 Initial commit; dumping current device files
    [PHY10CMCX-BAS.step, PHY10CMCX-BOD.step, PHY10CMCX-CAP.step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]
2026-07-08 Added all hardware modules and adaptor files
    [1x1-adaptor.kicad_pcb, 1x1-adaptor.kicad_sch, 4x1-adaptor.kicad_pcb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]
2026-07-14 converted remaining data files to CSV
    [recordings-1.csv, recordings-2.csv, recordings-3.csv]
2026-07-19 Added code for equivalent circuit simulations
2026-08-06 Updating device sweep data to include missing sweeps
